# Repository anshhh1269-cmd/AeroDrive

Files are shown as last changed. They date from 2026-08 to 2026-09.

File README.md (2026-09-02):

# AeroDrive

AeroDrive is a standalone, ESP32-powered smart dashboard that uses Wi-Fi to turn live traffic and weather data into physical animations (a spinning wheel and turbine) and screen updates across four custom modes; printable link: https://www.printables.com/model/1825933-aerodrive

# Reason

Now, why did I choose to build AeroDrive over all the other amazing projects? First obvi I wanted to find something that would encompass both my passions for aerospace and automotive engineering into a single physical project. Second, I wanted to take my CAD and 3D printing skills to the next level by designing a custom chassis that feels like a cross between a cockpit instrument panel and a high-performance supercar dash—something functional, sleek, and genuinely cool to have on a desk.

# The Functionality

Firstly, hardware: AeroDrive contains an ESP32 microcontroller, a high-refresh display panel, and custom physical inputs—each mapped to simulate real vehicle and flight telemetry control;

**Switch 1 (Traffic Mode)**: Revs an engine sound on startup, then continuously spins the car wheel fast for clear roads and slow for heavy traffic.

**Switch 2 (Wind Mode)**: Displays live weather on the screen and briefly spools up the turbine fan whenever real outdoor wind gusts occur.

**Switch 3**: A 25-minute Pomodoro timer that mutes all motors for quiet studying, with double-tap display dimming and a long-press demo sweep.

The ESP32 device connects to your local Wi-Fi network and establishes a secure connection to fetch live environmental or telemetry data via background HTTP requests. It parses real-time JSON payloads containing parameters like speed, acceleration vectors, temperature metrics, and system status.

Then, the processed data is pushed directly to the display controller to update the custom retro-style dials, digital needles, and live graphs on the screen. Pressing any of the physical switches triggers immediate GPIO interrupts to execute custom routines, toggle display states, or send control commands back through the system.

# The Schematics and PCB











# 3D Model







**Public Link**: https://a360.co/4wyEuVF

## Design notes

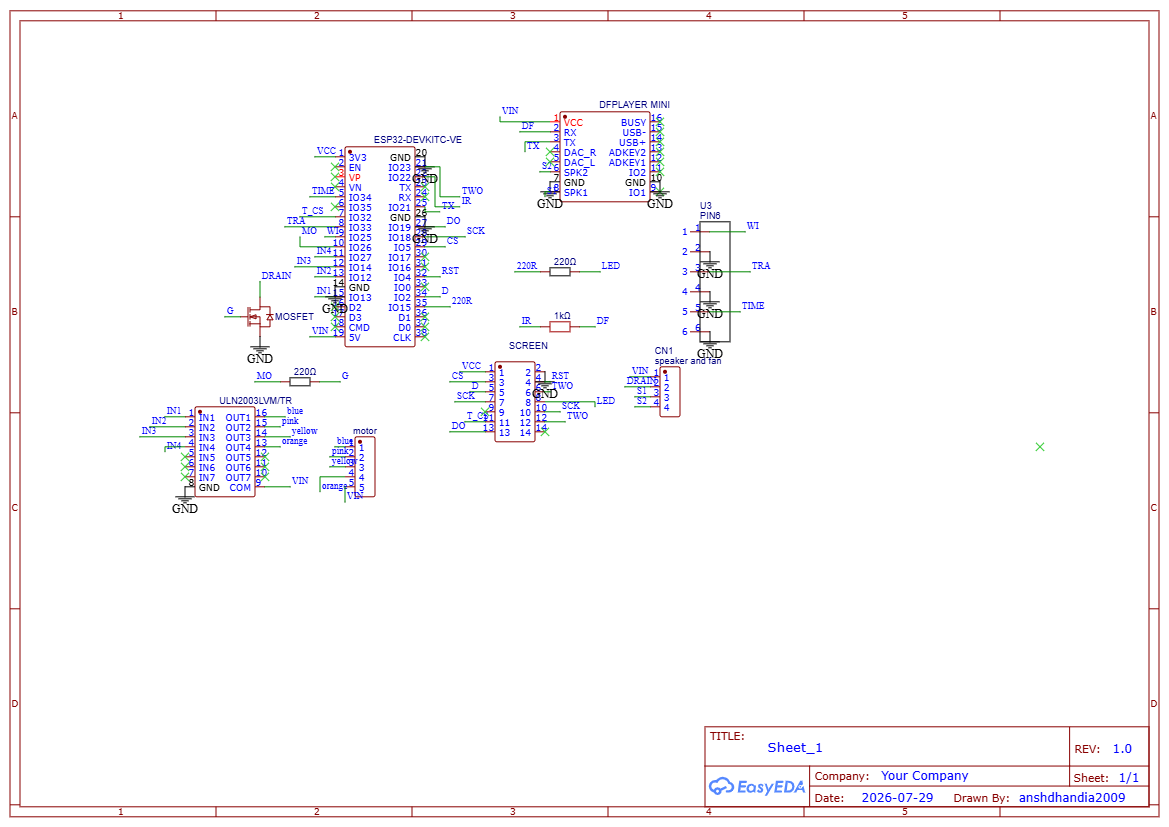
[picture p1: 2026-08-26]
PCB and Schematics/Schematics.png

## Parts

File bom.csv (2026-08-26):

Item | Quantity | Use | Cost(thb)+shipping | Link
ESP32-DevKitC Board | 1 | Microcontroller | 100 | https://shopee.co.th/EZY-ESP32-S3-N16R8-%E0%B8%9A%E0%B8%AD%E0%B8%A3%E0%B9%8C%E0%B8%94%E0%B8%9E%E0%B8%B1%E0%B8%92%E0%B8%99%E0%B8%B2-DevKitC-1-WROOM-1-N16R8-%E0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
ILI9341 TFT Touchscreen | 1 | The color display screen with touch controller support | 180 | https://shopee.co.th/%E0%B9%82%E0%B8%A1%E0%B8%94%E0%B8%B9%E0%B8%A5%E0%B8%9E%E0%B8%AD%E0%B8%A3%E0%B9%8C%E0%B8%95%E0%B8%AD%E0%B8%99%E0%B8%B8%E0%B8%81%E0%B8%A3%E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
28BYJ-48 Stepper Motor with ULN2003 Driver Board | 1 | Used for the mechanical dashboard gauge/wheel movement | 90 | https://shopee.co.th/ULN2003-Driver-5V-4-Phase-Stepper-Motor-%E0%B8%AA%E0%B8%B3%E0%B8%AB%E0%B8%A3%E0%B8%B1%E0%B8%9A-Arduino-%E0%B8%A1%E0%B8%B5%E0%B9%80%E0%B8%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
5V Mini Turbine / Blower Fan | 1 | physical fan | 70 | https://shopee.co.th/%E0%B8%9E%E0%B8%B1%E0%B8%94%E0%B8%A5%E0%B8%A1-DC12V-DC5V-%E0%B8%A1%E0%B8%B5%E0%B8%AB%E0%B8%A5%E0%B8%B2%E0%B8%A2%E0%B8%82%E0%B8%99%E0%B8%B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
2N7000 N-Channel MOSFET | 1 | controller for fan | 55 | https://shopee.co.th/2N7000-N-Channel-MosFET-(5%E0%B8%8A%E0%B8%B4%E0%B9%89%E0%B8%99)-i.76886102.2725729435
DFPlayer Mini MP3 Module | 1 | play engine sounds | 70 | https://shopee.co.th/Mcxk-e-DFPlayer-%E0%B8%9A%E0%B8%AD%E0%B8%A3%E0%B9%8C%E0%B8%94%E0%B9%82%E0%B8%A1%E0%B8%94%E0%B8%B9%E0%B8%A5%E0%B9%80%E0%B8%84%E0%B8%A3%E0%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
Speaker | 1 | loaded with audio tracks | 60 | https://shopee.co.th/%E0%B8%A5%E0%B8%B3%E0%B9%82%E0%B8%9E%E0%B8%87-3W-4%E0%B9%82%E0%B8%AD%E0%B8%AB%E0%B9%8C%E0%B8%A1-%E0%B8%82%E0%B8%99%E0%B8%B2%E0%B8%94-1.5-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
Switches | 3 | control mode | 70 | https://shopee.co.th/(%E0%B8%8A%E0%B8%B8%E0%B8%94-10-%E0%B8%95%E0%B8%B1%E0%B8%A7)-Outemu-Switch-Keyboard-%E0%B8%AA%E0%B8%A7%E0%B8%B4%E0%B8%95%E0%B8%8B%E0%B9%8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
Resistors | 2 | 220 and 1k | 50 | https://shopee.co.th/%E0%B8%95%E0%B8%B1%E0%B8%A7%E0%B8%95%E0%B9%89%E0%B8%B2%E0%B8%99%E0%B8%97%E0%B8%B2%E0%B8%99-1-4W-Resistor-1-4W-220-1k-10k-%E0%B9%82%E0%B8%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
PCB | 1 | Component wiring | 260 | -
Total Price | 11 | - | 1005 | -

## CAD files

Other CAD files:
3D Model/Aerodrive.stp

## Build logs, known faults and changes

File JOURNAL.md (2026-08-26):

# AeroDrive

AeroDrive is a standalone, ESP32-powered smart dashboard that uses Wi-Fi to turn live traffic and weather data into physical animations (a spinning wheel and turbine) and screen updates across four custom modes

# 2026-08-26: final github repo

**Total time spent: 0.45 hours**

aight so i edited everything in github and added the source files for 3d, pcb and firmware..

also added some more pics of 3d model in the readme 

thats it for this proj..putting in review now :)



# 2026-08-26: did the firmware

**Total time spent: 2.1 hours**

got the full code up and running for the aeroDrive today. the main goal was to hook up our custom PCB to the ILI9341 screen, pull real-time API data over Wi-Fi, and trigger physical stuff like our turbine fan and engine sound effects using both hardware switches and touch inputs.

How the Physical Controls Work

I set up the code so we have tactile switches for quick cockpit control, but also touch gestures directly on the screen for extra settings.

The first switch toggles Traffic Mode. When you flip it, the ESP32 sends a quick command to the DFPlayer Mini over serial pins (IO21/IO22) to play an engine rev sound on the speaker then show live traffic stuff..

The second switch puts it into Wind Mode. The code pulls live wind speed and gust data from the Open-Meteo API. If live gusts go over 15 km/h, the ESP32 sends pin IO13 HIGH, opening our 2N7000 MOSFET gate to spool up the physical 5V turbine fan; can also tap the screen to trigger a manual 5-second fan boost or swap speed units.

The third switch starts a 25-minute Pomodoro focus timer. It instantly kills the fan, stops the stepper motor, and mutes the audio module.

okay and also i wanted to use google map api like in my firmware there is a line of code for the google map API but because it just requires a card no money tho so i didnt out the card yet..will check it out later :)



# 2026-08-17: pcb in fusion

**Total time spent: 1.2 hours**

so i had to check the holes made in fusion if they align with the real pcb..so obvi i need a pro easyeda account to do it in step so i had to do the .obj which took the pcb into a mesh..used the convert mesh thing and it became a body..

next thing was that this was wayy too big..idk i searched it is supposed to import stuff with a scale of one but this was huge..so i had to figure out the scale which i did and then used the move feature..

the move feature took many tries because the screw holes on this pcb wasnt like perfect holes idk why the center of the hole wasnt seletcing so i had to do many trails and errors..more time was spent finding my 3d model when im zoomed in on the pcb cause they were very far apart and size diff before the scale..

i did use the move thingy successfully then i imported the m3 screws and aligned them on two holes diagonally because we dont need four screws ngl..

thats it for this session..next would be working on the repo like bom and 3d stuff

dont have lapse for this cause lapse wasnt allowing me to record in fusion..but honestly this took me around one hr cause it made it kinda difficult..



# 2026-08-15: screws and pcb

**Total time spent: 1.1 hours**

so basically this session was to add screw holes on my 3d enclosure..now the pcb was kinda quite big than the space my 3d enclosure had for the pcb so i had to remove the holes again and edit the whole thing in easyeda pcb editor...

after doing that i used a measure and measured the length and the width and create 3mm holes 5mm deep for the screws to go in..i am struggling to add the pcb just to showcase that the holes are fine so i might not be able to do it..

thats it for tdy

lapse link: https://lapse.hackclub.com/timelapse/Gh2aqhBUK-Ux



# 2026-08-14: just made readme

**Total time spent: 0.567 hours**

so i wrote the readme for the github repo took some time cause i had to get the info for the switches again cause i kinda forgot :(

i have added all the pcb pics but 3d enclosure is still left because i have to make screw holes for the pcb in the enclosure which will take some time..

thats it 



# 2026-08-09: last part for the pcb :)

**Total time spent: 1 hour**

so basically i had fogotten to add the six pin header component for the three switches so its easy to connect. found many error going through that process but it came out perfectly i think with no DRC errors; however i have also started seeing the best website to order pcbs form which is cheap and can ship to my location :)

thats it for tdy

lapse link: https://lapse.hackclub.com/timelapse/abz-Fy-Vbi5F



# 2026-08-08: time for the pcbbb

**Total time spent: 1.1 hours**

so tdy was finishing up the schematics and also the pcb; so basically i got all the components together and routed all the connections for the pcb editor; DRC errors are zero :)

also did the copper area for gnd and also the 3d view of it looks amazing..i think next is pcb and finishing up the github before this is ready for shipping :)

lapse: https://lapse.hackclub.com/timelapse/hXL5Sw_q_Uqc





# 2026-08-04: schematic finished

**Total time spent: 0.35 hours**

yup, added all the crosses and also added header pins for the external components: fan, speaker and stepper motor



# 2026-08-04: schematic part 2

**Total time spent: 1.75 hours**

aight so im using easyeda for this instead of kicad idk why just doing it..

so i had put the wrong esp32 cause it didnt have 5V so that took a a lot of time to replace but im done rn for the schematic..next thing is for pcb..

however theres external connectors like fan, motor and speaker..ai told me to make header pins so maybe ill do tht or just leave it as it is and not cross them out but i might as well add the header pins lets see

thats it..i ahve added lapse links

https://lapse.hackclub.com/timelapse/jDW9MZFCGTUQ

https://lapse.hackclub.com/timelapse/JVzdDjOY-GFX



# 2026-07-30: worked in easyeda

**Total time spent: 0.8 hours**

so basically i had to start the wiring tdy..used easyeda and imported the player, the speaker, esp32, tft screen, mosfet and resistors..

now i wanted to try a touchscreen tft component so i asked AI what could be the features if i used touch...it wouldn't be much, but it would be cool tho

so the touch screen would basically just control the locations for the traffic input the user wants, along with the study timer..didnt do much research yet but still doing it..

this session did very little wiring, only the esp32 one side so ill work on it later..



lapse: https://lapse.hackclub.com/timelapse/-4e8cCRhQGJV

# 2026-07-26: added switches

**Total time spent: 0.67 hours**

so the next thing was to work on the switches..it was quite simple to make the switches holes which was 3 on the top face of the main body, which took around 20 ish mins..

after that i had to figure out the purpose..the main goal was to hv something that connected with real-world live data and also doesn't become a headache if put near a study table..so the purposes of the switches are as follows:

Switch 1 (Traffic Mode): Revs an engine sound on startup, then continuously spins the car wheel fast for clear roads and slow for heavy traffic.

Switch 2 (Wind Mode): Displays live weather on the screen and briefly spools up the turbine fan whenever real outdoor wind gusts occur.

Switch 3 A 25-minute Pomodoro timer that mutes all motors for quiet studying, with double-tap display dimming and a long-press demo sweep.



# 2026-07-26: figured out wheel movement (part 2)

**Total time spent: 2.3 hours**

soo left the project for some while to focus on my other build proj...

checked the motor once again and i noticed a gap; the motor shaft wasnt fully inside the hole made, the hole was bigger than expected..

so i went back to the timeline, checked the radius of the curved part of the shaft which turned out to be 2.50mm, so i used filet for the rectangle hole and made it 1.25mm on both sides...now this was a grave mistake

the hole was no so big on the width side, rather than the length and now it looked even worse so 45 mins into the garbage..then i finally used my mind used project and made the hole exactly the one which was needed..

so this kinda took some time to do since i had to go back to the timeline and also find and delete any extrude made on the hole so that the project option remains valid. 







# 2026-07-16: figured out the wheel's movement

**Total time spent: 2.2 hours**

today was the day where I was checking how the wheel would move, because the wheel didn't have any open hole that would allow the motor shaft to turn the wheel. 

so basically the motor I was using was the 28BYG-48, and I asked Gemini for the exact dimensions of the motor shaft, which turned out to be not a simple rectangle but one with curved ends on two sides..

so i extruded a cylinder on the center of the wheel to 9 mm and then took the dimensions from Gemini to make the curved rectangle and extruded it to negative 8.5mm..

however, i still needed confirmation...so i went onto GrabCAD, found the exact model, and imported it right onto the hybrid assembly..after checking the exact size of the curved rectangle needed i was finally done for tdy..

tmr is figuring out how to screw the motor onto something so that when the wheel spins, it just doesn't come out of the main body while spinning. 

thats it for tdy :)

Screenshot 2026-07-15 121427.png

Screenshot 2026-07-15 121534.png

Screenshot 2026-07-15 210558.png

# 2026-07-15: finished the back cover

**Total time spent: 1.89 hours**

so the back cover was such a headache because the main body is fully curved...not like my other projects...so I first made the outline of the back cover through sketching and taking in all of the dimensions.

Then I had to fillet it...obviously I had extruded the second inner rectangle more than everything else, so the cover fits on perfectly.

after trying to make it curve, idk why I didn't know what corner to choose for the fillet option, as the curve wasn't coming to the extent that I wanted it to. took a day off and thought about which line to take..and then it just snapped

the line should be the inside line of the extrude, and when I finally tried it, it worked!!

took a lot of time for the back cover ngl :(

thats it for tdy :)

Screenshot 2026-07-15 112436.png

Screenshot 2026-07-15 112851.png

Screenshot 2026-07-15 112901.png

# 2026-07-12: made the CAD better

**Total time spent: 2.067 hours**

so after researching for more features; my mind came across adding three switches; one of the switch would translate the screen for showing real time traffic stats and some local place journey time..second button would be for wind speed; and the traffic and wind speed would translate to the speed of the wheel turning and the fan behind the turbine.

now in fusion 360, i used shell and then made the holes bigger; added the imports and then checked yet again that the holes were too big and just kept on doing trial and error to perfect the scale factor of the imports..

reached on smthng then found the correct tft screen needed..and made borders so that the only thing visible outside would be the screen outline and nothing else..i think it looks a bit professional too now

second thing the third switch would be alarm for some kind so i would be also using a buzzer just maybe btw...if i have space remaining

the next thing to do is to draw the cut outs for the switches, then move onto the wiring diagram after making CAD better. 

thats it for tdy :)

Screenshot 2026-07-13 001200.png

Screenshot 2026-07-13 001251.png

# 2026-07-12: started aerodrive 

**Total time spent: 1.56 hours**

so i first started aerodrive..looking at all features I can build by using AI; including the shape, the parts needed.

so first i went to grabcad...and i searched for aircraft turbines, which took some while to get the correct one along with the car wheels; then thought of having some action from these parts; so basically the car wheel spins and the turbines will have a fan behind it which would spin too according to the firmware which is a secret rn..

and then went to fusion 360, started a new project..and created a rectangle and use filet; along with importing these parts and creating the circles and rectangles for the input..

lastly, i used shell for the first time to remove the back cover and then hope to create a back cover

Screenshot 2026-07-12 153239.png

Screenshot 2026-07-12 230632.png

Screenshot 2026-07-12 230612.png

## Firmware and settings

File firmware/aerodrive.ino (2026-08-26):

#include <WiFi.h>
#include <HTTPClient.h>
#include <ArduinoJson.h>
#include <TFT_eSPI.h>
#include <HardwareSerial.h>
#include <DFRobotDFPlayerMini.h>
#include "time.h"

// --- WIFI & API CONFIGURATION ---
const char* ssid       = "someone";
const char* password   = "rivaanretard2";

const char* ntpServer  = "pool.ntp.org";
const long  gmtOffset_sec = 25200; // GMT+7 (Bangkok)
const int   daylightOffset_sec = 0;

// Google Maps Distance Matrix API Configuration
const String GOOGLE_API_KEY = "YOUR_GOOGLE_MAPS_API_KEY";
const String ORIGIN         = "13.7563,100.5018"; // Start Coords (Lat,Lon)

// Saved Destinations Array for Touch Cycling
const String DESTINATIONS[3] = {"13.6900,100.7501", "13.7466,100.5349", "13.8000,100.5500"};
const String DEST_NAMES[3]   = {"AIRPORT", "CENTER", "NORTH HQ"};
int currentDestIdx = 0;

// Open-Meteo Weather Coordinates
const String LATITUDE  = "13.7563";
const String LONGITUDE = "100.5018";

// --- PIN DEFINITIONS (SCHEMATIC MATCH) ---
#define PIN_SW_TRA    32
#define PIN_SW_WI     33
#define PIN_SW_FOCUS  39

#define PIN_FAN       13
#define PIN_TFT_BL    12
#define TOUCH_CS      35 // T_CS on U8 header

#define IN1 14
#define IN2 27
#define IN3 26
#define IN4 25

// --- HARDWARE OBJECTS ---
TFT_eSPI tft = TFT_eSPI();
HardwareSerial dfSerial(1);
DFRobotDFPlayerMini dfplayer;

// --- STATE MANAGEMENT ---
enum OperatingMode { MODE_DEFAULT_CLOCK, MODE_TRAFFIC, MODE_WIND, MODE_POMODORO };
OperatingMode currentMode = MODE_DEFAULT_CLOCK;

// Stepper Motor Sequence (Half-Step)
const int stepPins[4] = {IN1, IN2, IN3, IN4};
const int stepMatrix[8][4] = {
  {1,0,0,0}, {1,1,0,0}, {0,1,0,0}, {0,1,1,0},
  {0,0,1,0}, {0,0,1,1}, {0,0,0,1}, {1,0,0,1}
};
int currentStep = 0;

// System Variables
bool isDimmed = false;
unsigned long pomodoroStart = 0;
bool isPomodoroPaused = false;
unsigned long pomodoroPauseOffset = 0;
const unsigned long POMODORO_DURATION = 25 * 60 * 1000;

unsigned long lastPressFocus = 0;
int tapCountFocus = 0;
unsigned long lastTimeUpdate = 0;
unsigned long lastTouchTime = 0;

// Theme Colors for Default Clock Touch Cycling
uint16_t clockThemeColors[4] = {TFT_CYAN, TFT_YELLOW, TFT_RED, TFT_GREEN};
int themeIdx = 0;

// Unit Switcher for Wind Mode (0: km/h, 1: m/s, 2: knots)
int windUnitMode = 0; 
unsigned long manualFanBoostEnd = 0; // Manual Fan Touch Timer

// Live API Data & Timers
int liveTravelTimeMin = 25;
int liveNormalTimeMin = 25;
float liveWindSpeedKmh = 0.0;
float liveWindGustKmh  = 0.0;

unsigned long lastTrafficFetch = 0;
unsigned long lastWindFetch    = 0;
const unsigned long API_INTERVAL = 300000; // 5-minute background refresh

void setup() {
  Serial.begin(115200);

  // Pin Modes
  pinMode(PIN_SW_TRA, INPUT_PULLUP);
  pinMode(PIN_SW_WI, INPUT_PULLUP);
  pinMode(PIN_SW_FOCUS, INPUT_PULLUP);
  
  pinMode(PIN_FAN, OUTPUT);
  digitalWrite(PIN_FAN, LOW);

  pinMode(PIN_TFT_BL, OUTPUT);
  digitalWrite(PIN_TFT_BL, HIGH);

  for(int i = 0; i < 4; i++) pinMode(stepPins[i], OUTPUT);

  // Initialize Display
  tft.init();
  tft.setRotation(1);
  tft.fillScreen(TFT_BLACK);

  // Wi-Fi Connection
  WiFi.begin(ssid, password);
  while (WiFi.status() != WL_CONNECTED && millis() < 10000) {
    delay(250);
  }

  // Time Sync
  configTime(gmtOffset_sec, daylightOffset_sec, ntpServer);

  // Initialize Audio Module
  dfSerial.begin(9600, SERIAL_8N1, 22, 21);
  if (dfplayer.begin(dfSerial)) {
    dfplayer.volume(20);
  }

  // Initial Data Fetch
  fetchLiveTrafficData();
  fetchLiveWindData();

  tft.fillScreen(TFT_BLACK);
}

void loop() {
  handleSwitchInputs();
  handleTouchInputs();

  // Background API Refresh
  if (millis() - lastTrafficFetch > API_INTERVAL) fetchLiveTrafficData();
  if (millis() - lastWindFetch > API_INTERVAL)    fetchLiveWindData();

  // Mode Handlers
  switch(currentMode) {
    case MODE_DEFAULT_CLOCK:
      updateDefaultClockUI();
      break;
    case MODE_TRAFFIC:
      runTrafficMode();
      break;
    case MODE_WIND:
      runWindMode();
      break;
    case MODE_POMODORO:
      runPomodoroMode();
      break;
  }
}

// --- TOUCHSCREEN CONTROL ENGINE ---
void handleTouchInputs() {
  uint16_t x = 0, y = 0;

  // Read Touch Controller (Threshold pressure ~600)
  if (tft.getTouch(&x, &y, 600)) {
    if (millis() - lastTouchTime < 350) return; // Debounce
    lastTouchTime = millis();

    // Universal Top Banner Touch: Tap to force API update or toggle modes
    if (y < 40) {
      if (currentMode == MODE_TRAFFIC) fetchLiveTrafficData();
      else if (currentMode == MODE_WIND) fetchLiveWindData();
      else {
        currentMode = static_cast<OperatingMode>((currentMode + 1) % 4);
        tft.fillScreen(TFT_BLACK);
      }
      return;
    }

    // DEFAULT MODE TOUCH: Tap clock to cycle themes
    if (currentMode == MODE_DEFAULT_CLOCK) {
      themeIdx = (themeIdx + 1) % 4;
      tft.fillScreen(TFT_BLACK);
    }
    
    // TRAFFIC MODE TOUCH: Tap destination label to switch route target
    else if (currentMode == MODE_TRAFFIC) {
      if (y > 150) {
        currentDestIdx = (currentDestIdx + 1) % 3;
        fetchLiveTrafficData(); // Immediate re-fetch for new coordinates
        tft.fillScreen(TFT_BLACK);
      }
    }

    // WIND MODE TOUCH: Tap center screen to activate 5s turbine boost / change units
    else if (currentMode == MODE_WIND) {
      if (y > 60 && y < 140) {
        windUnitMode = (windUnitMode + 1) % 3; // Toggle km/h -> m/s -> knots
      } else if (y >= 140) {
        manualFanBoostEnd = millis() + 5000; // 5-second manual turbine boost
      }
    }

    // POMODORO MODE TOUCH: Tap center timer to Pause/Resume
    else if (currentMode == MODE_POMODORO) {
      if (y > 60 && y < 180) {
        isPomodoroPaused = !isPomodoroPaused;
      }
    }
  }
}

// --- API FETCHERS ---
void fetchLiveTrafficData() {
  if (WiFi.status() == WL_CONNECTED) {
    HTTPClient http;
    String url = "https://maps.googleapis.com/maps/api/distancematrix/json?origins=" + ORIGIN + 
                 "&destinations=" + DESTINATIONS[currentDestIdx] + 
                 "&departure_time=now&key=" + GOOGLE_API_KEY;

    http.begin(url);
    if (http.GET() == HTTP_CODE_OK) {
      String payload = http.getString();
      DynamicJsonDocument doc(2048);
      deserializeJson(doc, payload);

      int trafficSec = doc["rows"][0]["elements"][0]["duration_in_traffic"]["value"];
      int normalSec  = doc["rows"][0]["elements"][0]["duration"]["value"];

      if (trafficSec > 0) liveTravelTimeMin = trafficSec / 60;
      if (normalSec > 0)  liveNormalTimeMin = normalSec / 60;
    }
    http.end();
  }
  lastTrafficFetch = millis();
}

void fetchLiveWindData() {
  if (WiFi.status() == WL_CONNECTED) {
    HTTPClient http;
    String url = "https://api.open-meteo.com/v1/forecast?latitude=" + LATITUDE + 
                 "&longitude=" + LONGITUDE + 
                 "&current=wind_speed_10m,wind_gusts_10m";

    http.begin(url);
    if (http.GET() == HTTP_CODE_OK) {
      String payload = http.getString();
      DynamicJsonDocument doc(1024);
      deserializeJson(doc, payload);

      liveWindSpeedKmh = doc["current"]["wind_speed_10m"];
      liveWindGustKmh  = doc["current"]["wind_gusts_10m"];
    }
    http.end();
  }
  lastWindFetch = millis();
}

// --- SWITCH INTERRUPT & GESTURE LOGIC ---
void handleSwitchInputs() {
  if (digitalRead(PIN_SW_TRA) == LOW) {
    if (currentMode != MODE_TRAFFIC) {
      currentMode = MODE_TRAFFIC;
      initTrafficMode();
    }
    delay(200);
  } 
  else if (digitalRead(PIN_SW_WI) == LOW) {
    if (currentMode != MODE_WIND) {
      currentMode = MODE_WIND;
      initWindMode();
    }
    delay(200);
  }
  else if (digitalRead(PIN_SW_FOCUS) == LOW) {
    unsigned long pressTime = millis();
    while(digitalRead(PIN_SW_FOCUS) == LOW) {
      if (millis() - pressTime > 1500) {
        runDemoSweep();
        return;
      }
    }
    
    // Double Tap Backlight Dimming
    tapCountFocus++;
    if (tapCountFocus == 1) lastPressFocus = millis();
    if (tapCountFocus == 2 && (millis() - lastPressFocus < 400)) {
      isDimmed = !isDimmed;
      analogWrite(PIN_TFT_BL, isDimmed ? 30 : 255);
      tapCountFocus = 0;
    }

    if (currentMode != MODE_POMODORO) {
      currentMode = MODE_POMODORO;
      initPomodoroMode();
    }
  }

  if (millis() - lastPressFocus > 400) tapCountFocus = 0;
}

// --- LIVE TIME & DATE RENDERER ---
void drawTimeHeader(bool fullScreenClock) {
  struct tm timeinfo;
  if(!getLocalTime(&timeinfo)) return;

  char timeStr[10];
  char dateStr[20];
  strftime(timeStr, sizeof(timeStr), "%H:%M:%S", &timeinfo);
  strftime(dateStr, sizeof(dateStr), "%a, %b %d %Y", &timeinfo);

  if (fullScreenClock) {
    tft.setTextColor(clockThemeColors[themeIdx], TFT_BLACK);
    tft.drawString(timeStr, 20, 60, 7);
    tft.setTextColor(TFT_WHITE, TFT_BLACK);
    tft.drawString(dateStr, 40, 150, 4);
    tft.drawString("SYSTEM READY // AERODRIVE", 30, 200, 2);
  } else {
    tft.setTextColor(TFT_DARKGREY, TFT_BLACK);
    tft.drawString(String(timeStr) + " | " + String(dateStr), 10, 5, 2);
  }
}

// --- MODE 0: DEFAULT CLOCK ---
void updateDefaultClockUI() {
  if (millis() - lastTimeUpdate > 500) {
    drawTimeHeader(true);
    lastTimeUpdate = millis();
  }
  digitalWrite(PIN_FAN, LOW);
  stopMotor();
}

// --- MODE 1: TRAFFIC MODE ---
void initTrafficMode() {
  tft.fillScreen(TFT_BLACK);
  dfplayer.play(1);
  delay(1200);
}

void runTrafficMode() {
  drawTimeHeader(false);
  
  uint16_t statusColor = TFT_GREEN;
  int motorSpeedDelay = 3;

  if (liveTravelTimeMin > liveNormalTimeMin + 15) {
    statusColor = TFT_RED;
    motorSpeedDelay = 12;
  } else if (liveTravelTimeMin > liveNormalTimeMin + 5) {
    statusColor = TFT_YELLOW;
    motorSpeedDelay = 7;
  }

  tft.setTextColor(TFT_WHITE, TFT_BLACK);
  tft.drawString("LIVE COMMUTE ETA", 20, 30, 4);
  tft.setTextColor(statusColor, TFT_BLACK);
  tft.drawString(String(liveTravelTimeMin) + " MINS", 20, 70, 7);
  
  tft.drawSmoothArc(240, 160, 50, 40, 45, 315, statusColor, TFT_BLACK);
  tft.setTextColor(TFT_WHITE, TFT_BLACK);
  tft.drawString("TARGET: " + DEST_NAMES[currentDestIdx] + " [TAP]", 20, 160, 2);

  stepMotor(motorSpeedDelay);
}

// --- MODE 2: WIND MODE ---
void initWindMode() {
  tft.fillScreen(TFT_BLACK);
}

void runWindMode() {
  drawTimeHeader(false);

  bool isGusting = liveWindGustKmh > 15.0 || liveWindSpeedKmh > 15.0;
  bool isManualBoost = millis() < manualFanBoostEnd;

  // Unit Conversions
  float displayVal = liveWindSpeedKmh;
  String unitStr = " km/h";
  if (windUnitMode == 1) { displayVal *= 0.277778; unitStr = " m/s"; }
  else if (windUnitMode == 2) { displayVal *= 0.539957; unitStr = " knots"; }

  tft.setTextColor(TFT_CYAN, TFT_BLACK);
  tft.drawString("WIND TELEMETRY", 20, 30, 4);
  tft.setTextColor(TFT_WHITE, TFT_BLACK);
  tft.drawString("SPEED: " + String(displayVal, 1) + unitStr, 20, 80, 4);

  if (isGusting || isManualBoost) {
    tft.setTextColor(TFT_BLUE, TFT_BLACK);
    tft.drawString(isManualBoost ? "[ MANUAL BOOST ]" : "[ TURBINE SPOOLING ]", 20, 140, 4);
    digitalWrite(PIN_FAN, HIGH);
  } else {
    digitalWrite(PIN_FAN, LOW);
  }
}

// --- MODE 3: POMODORO FOCUS MODE ---
void initPomodoroMode() {
  pomodoroStart = millis();
  isPomodoroPaused = false;
  tft.fillScreen(TFT_BLACK);
  digitalWrite(PIN_FAN, LOW);
  stopMotor();
  dfplayer.stop();
}

void runPomodoroMode() {
  drawTimeHeader(false);

  unsigned long elapsed = isPomodoroPaused ? pomodoroPauseOffset : (millis() - pomodoroStart);
  if (elapsed > POMODORO_DURATION) elapsed = POMODORO_DURATION;

  unsigned long remaining = (POMODORO_DURATION - elapsed) / 1000;
  int mins = remaining / 60;
  int secs = remaining % 60;

  char timeBuffer[10];
  sprintf(timeBuffer, "%02d:%02d", mins, secs);

  tft.setTextColor(isPomodoroPaused ? TFT_YELLOW : TFT_ORANGE, TFT_BLACK);
  tft.drawString(isPomodoroPaused ? "PAUSED [TAP TO RESUME]" : "FOCUS TIMER [TAP PAUSE]", 20, 30, 4);
  tft.drawString(timeBuffer, 20, 80, 8);
}

// --- DEMO SWEEP ---
void runDemoSweep() {
  tft.fillScreen(TFT_WHITE);
  tft.setTextColor(TFT_BLACK, TFT_WHITE);
  tft.drawString("SYSTEM SWEEP DEMO", 20, 100, 4);

  digitalWrite(PIN_FAN, HIGH);
  for(int i = 0; i < 400; i++) stepMotor(2);
  digitalWrite(PIN_FAN, LOW);
  
  tft.fillScreen(TFT_BLACK);
}

// --- STEPPER MOTOR DRIVER ---
void stepMotor(int speedDelayMs) {
  for (int pin = 0; pin < 4; pin++) {
    digitalWrite(stepPins[pin], stepMatrix[currentStep][pin]);
  }
  currentStep = (currentStep + 1) % 8;
  delay(speedDelayMs);
}

void stopMotor() {
  for (int pin = 0; pin < 4; pin++) digitalWrite(stepPins[pin], LOW);
}

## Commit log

2026-08-26 Rename aerodrive (4).stp to 3D Model/Aerodrive.stp
    [Aerodrive.stp, aerodrive (4).stp]
2026-08-26 Rename Gerber_AeroDrive_PCB_AeroDrive_2_2026-08-14.zip to PCB and Schematics/Gerber.zip
2026-08-26 Rename OBJ_PCB_AeroDrive_2_2026-08-14.zip to PCB and Schematics/obj.zip
2026-08-26 Rename Schematic_AeroDrive_2026-08-26.png to PCB and Schematics/Schematics.png
